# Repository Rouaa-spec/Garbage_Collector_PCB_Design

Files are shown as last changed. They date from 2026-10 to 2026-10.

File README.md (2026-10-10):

# [Hardware Design] Carte Électronique de Contrôle — Robot Autonome Tri-Canettes

Ce dépôt rassemble les fichiers de conception matérielle de la carte de contrôle dédiée à un robot autonome de collecte et de tri de déchets. 

La carte centralise la gestion de l'alimentation (Li-Ion), le pilotage des moteurs DC et l'acquisition des capteurs de navigation sur bus partagés.

📌 **Statut du projet :** 
* 🟧 **Routage PCB (KiCad) :** En cours de réalisation...

---

## 🗺️ Architecture Système 

Le schéma architectural conçu pour la carte :

<p align="center">
Schéma fonctionnel
</p> 

---

## 🛠️ Spécifications & Choix des Composants

### 1. Unité de Traitement & Logique (MCU)
* **Microcontrôleur :** **STM32G431RBT6** (Cortex-M4, 170 MHz). Sélectionné pour ses timers avancés (gestion des moteurs et servo) et sa large connectivité matérielle.

### 2. Gestion de l'Énergie (Power Management)
* **Contrôleur de Charge :** **bq25896RTWR** (Switching Charger). Assure la charge rapide de la batterie Lithium-Ion via USB-C et la gestion dynamique du chemin de puissance (Power Path).
* **Jauge de Batterie :** **bq27220** (Fuel Gauge). Suivi précis de l'état de charge (SoC) via le bus I²C2.
* **Régulation :** LDO **AP2112K-3.3** (600mA) pour l'alimentation stable de la section logique et des capteurs.

### 3. Contrôle des Actionneurs (Motor Drive)
* **Driver Moteurs :** **DRV8833** (Double Pont en H) pour le pilotage de 2 motoréducteurs CC (CH-N20-3) via signaux PWM (`TIM1` et `TIM3`).
* **Servomoteur :** Sortie dédiée pour un **Servo MG90S** (Pince de préhension) piloté par le timer `TIM15`.

### 4. Acquisition Capteurs (Sensors)
Répartition sur trois bus physiques I²C indépendants pour éviter la saturation et les conflits d'adresses :
* **Bus I²C1 :** Centrale inertielle IMU **MPU-6050** (Odométrie).
* **Bus I²C2 :** Section Power Management (**bq27220** et **bq25896**).
* **Bus I²C3 :** Télémètres Laser ToF **VL53L0X** (Évitement d'obstacles) et capteur de couleur/proximité **APDS9960** (Tri des canettes). 
  * *Note de conception :* Les broches `XSHUT` des VL53L0X sont routées vers des GPIOs du STM32 pour configurer leurs adresses de manière logicielle et séquentielle.

---

## 📄 Dossier de Conception (Schématiques)

### Étage Microcontrôleur (MCU)
<p align="center">
MCU
</p> 

### Gestion d'Énergie (Power Management)
<p align="center">
Power Management
</p> 

### Bloc Capteurs (Sensors)
<p align="center">
Sensors
</p>

### Commande Moteurs (Motor Drive)
<p align="center">
Motor Drive
</p>

---

## 📂 Organisation du Dépôt

```text
├── 📂 Hardware/               # Fichiers sources CAO KiCad (.kicad_sch, .kicad_pcb en cours)
├── 📂 Documents/              
│   ├── 📄 Schematic_Print.pdf # Schématique complet 
└── 📄 README.md
```

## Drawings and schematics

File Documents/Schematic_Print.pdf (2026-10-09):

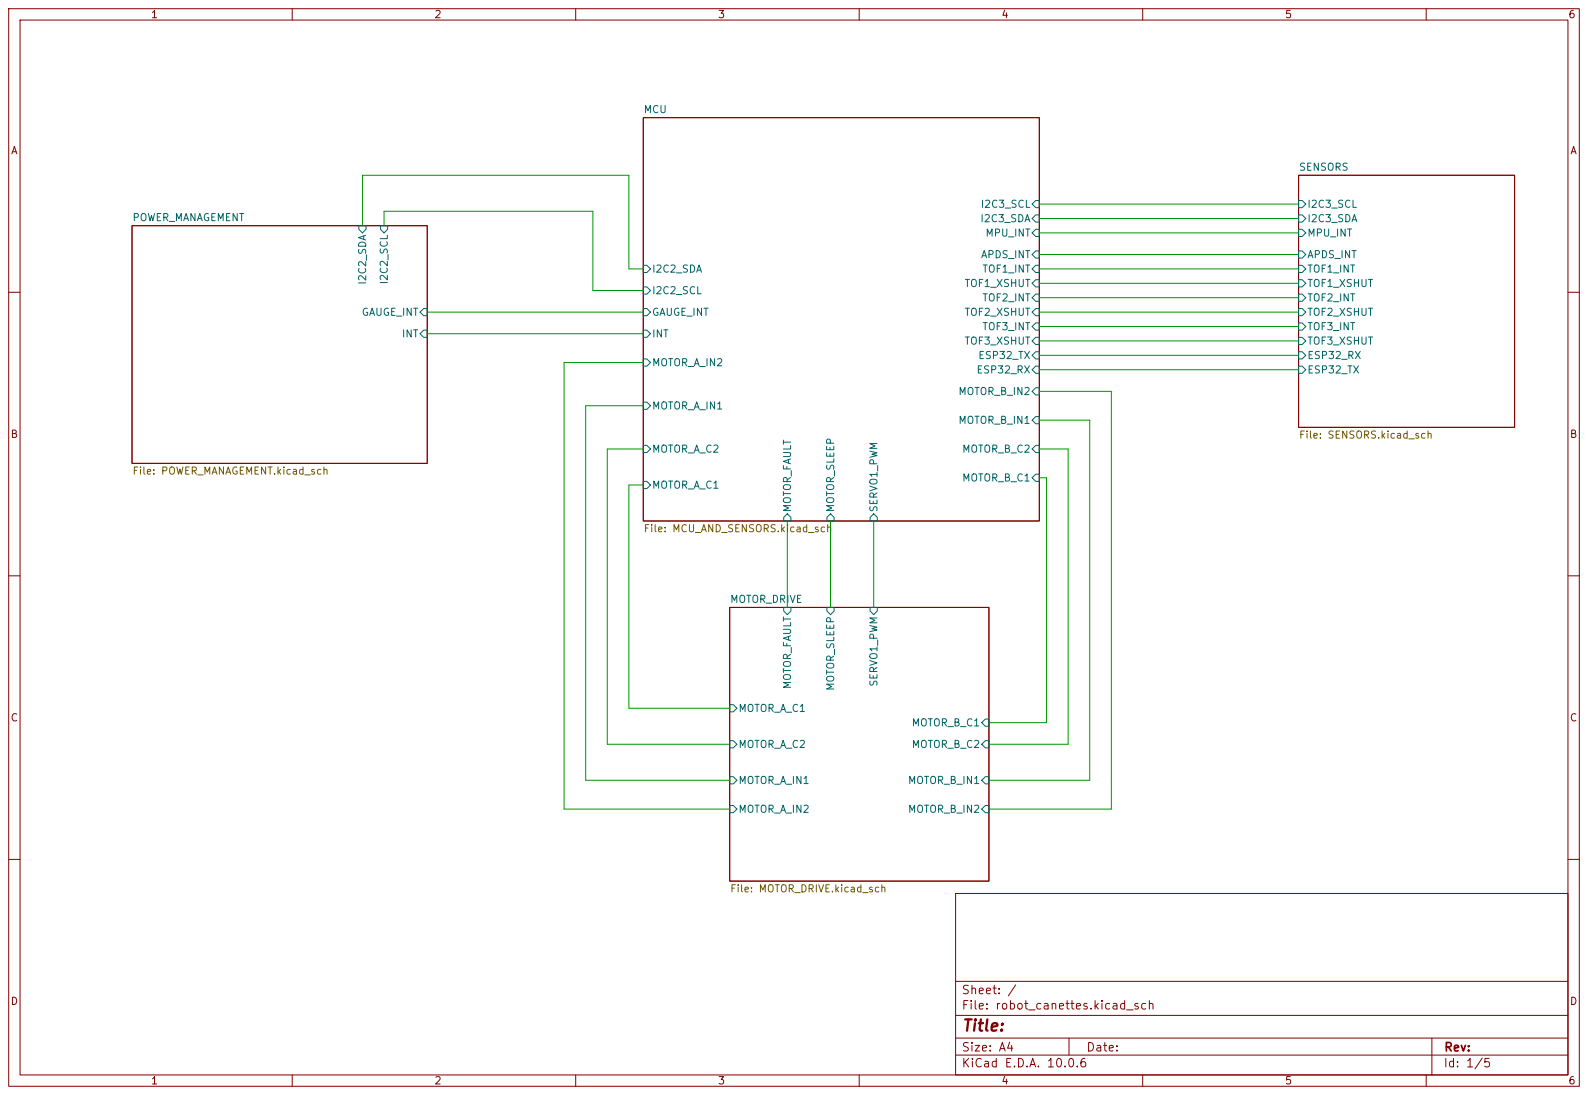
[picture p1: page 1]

Size: A4 | Rev:
KiCad E.D.A. 10.0.6 | Id: 1/5

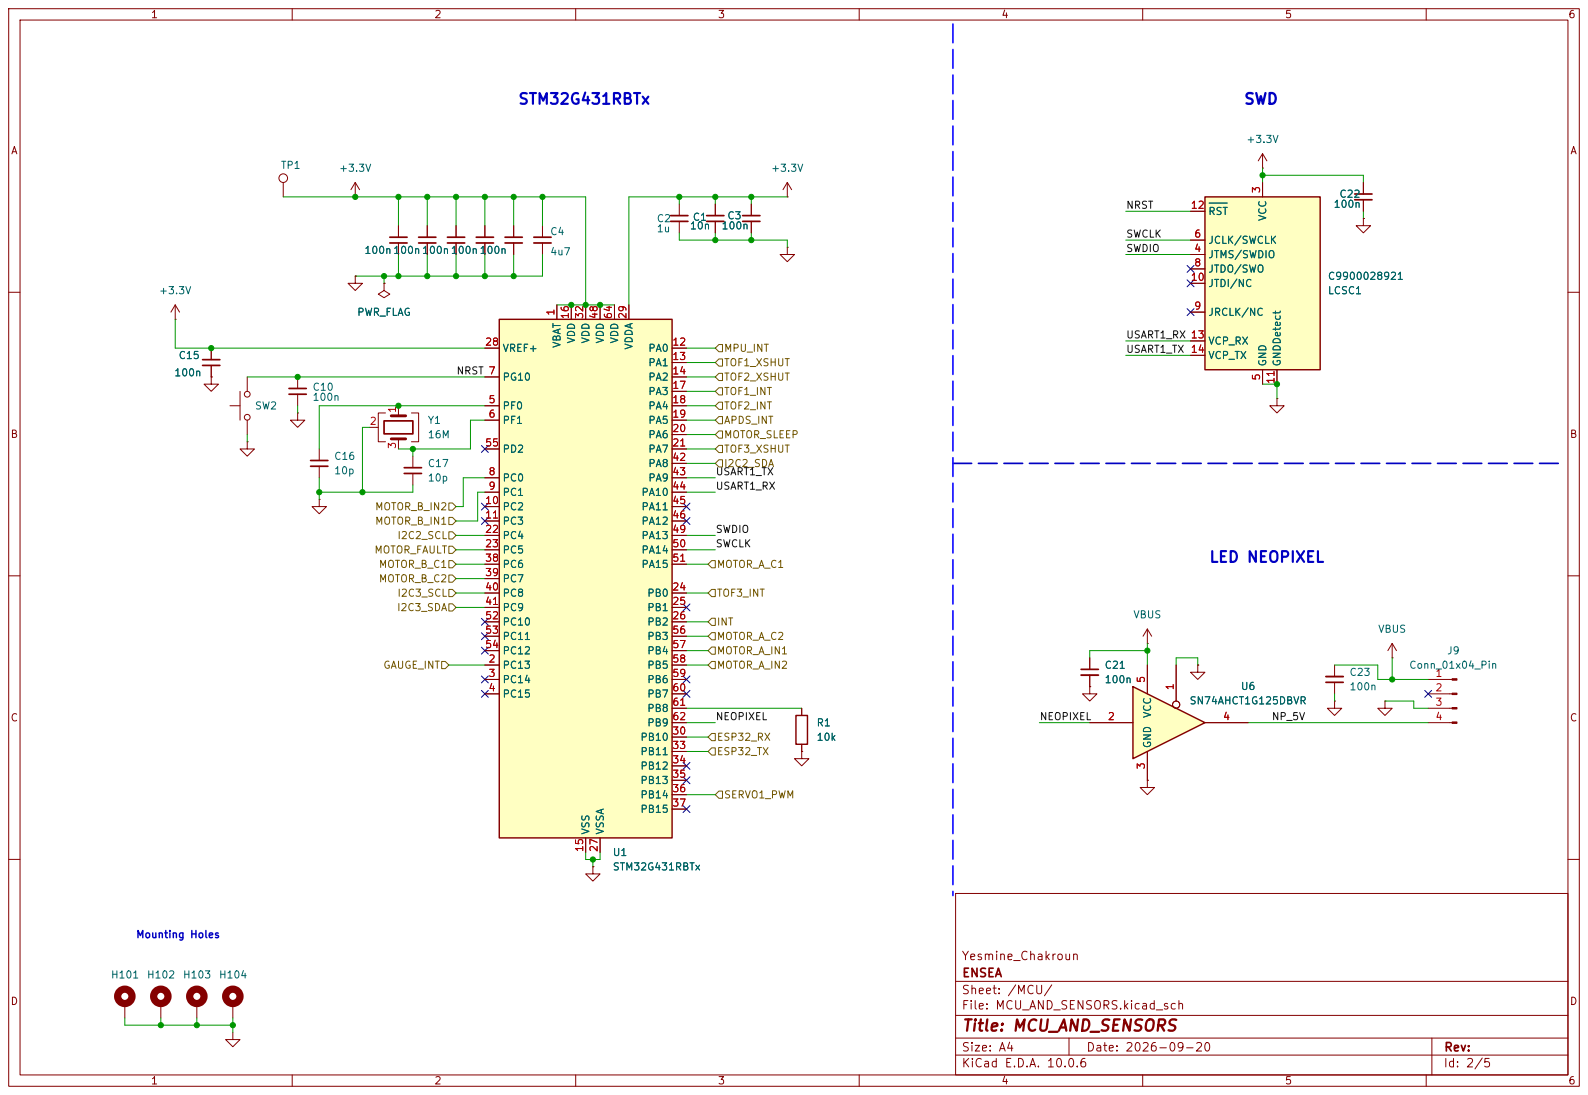
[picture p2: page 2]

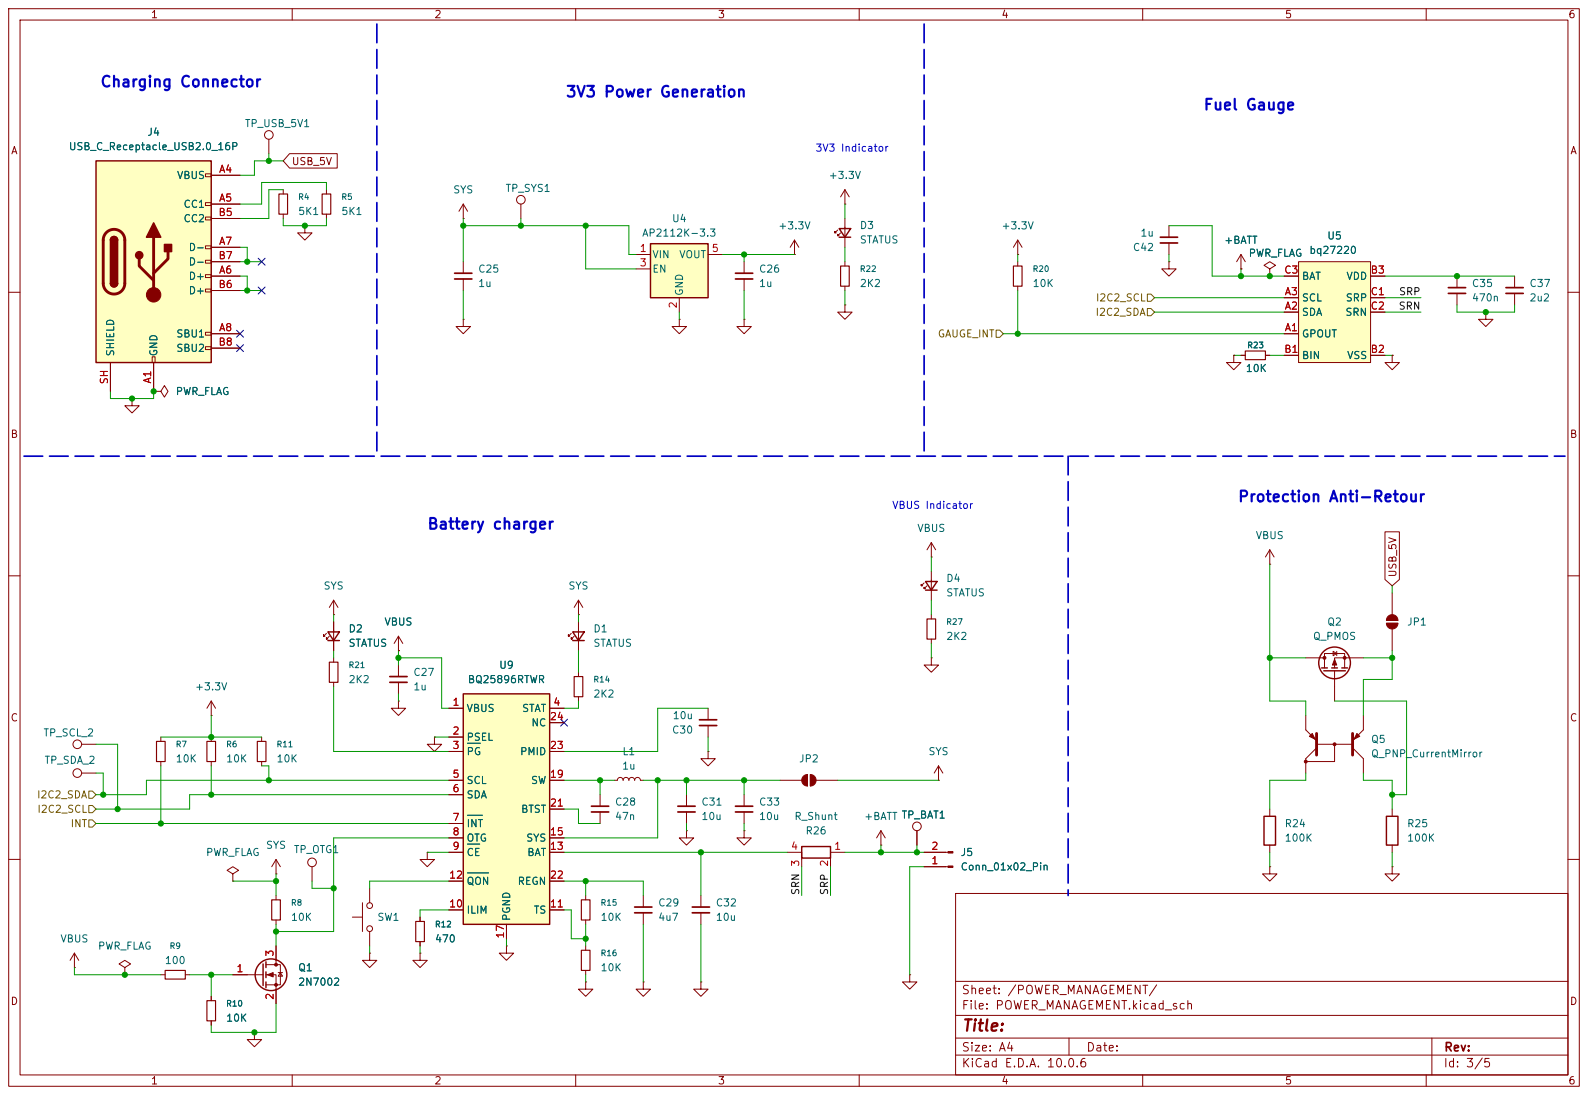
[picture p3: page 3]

VBUS Indicator 3V3 Power Generation

SW 19 BTST 21 REGN 22 PMID 23 NC 24 D2
STATUS

SW 19 BTST 21 REGN 22 PMID 23 NC 24 U9 BQ25896RTWR C27

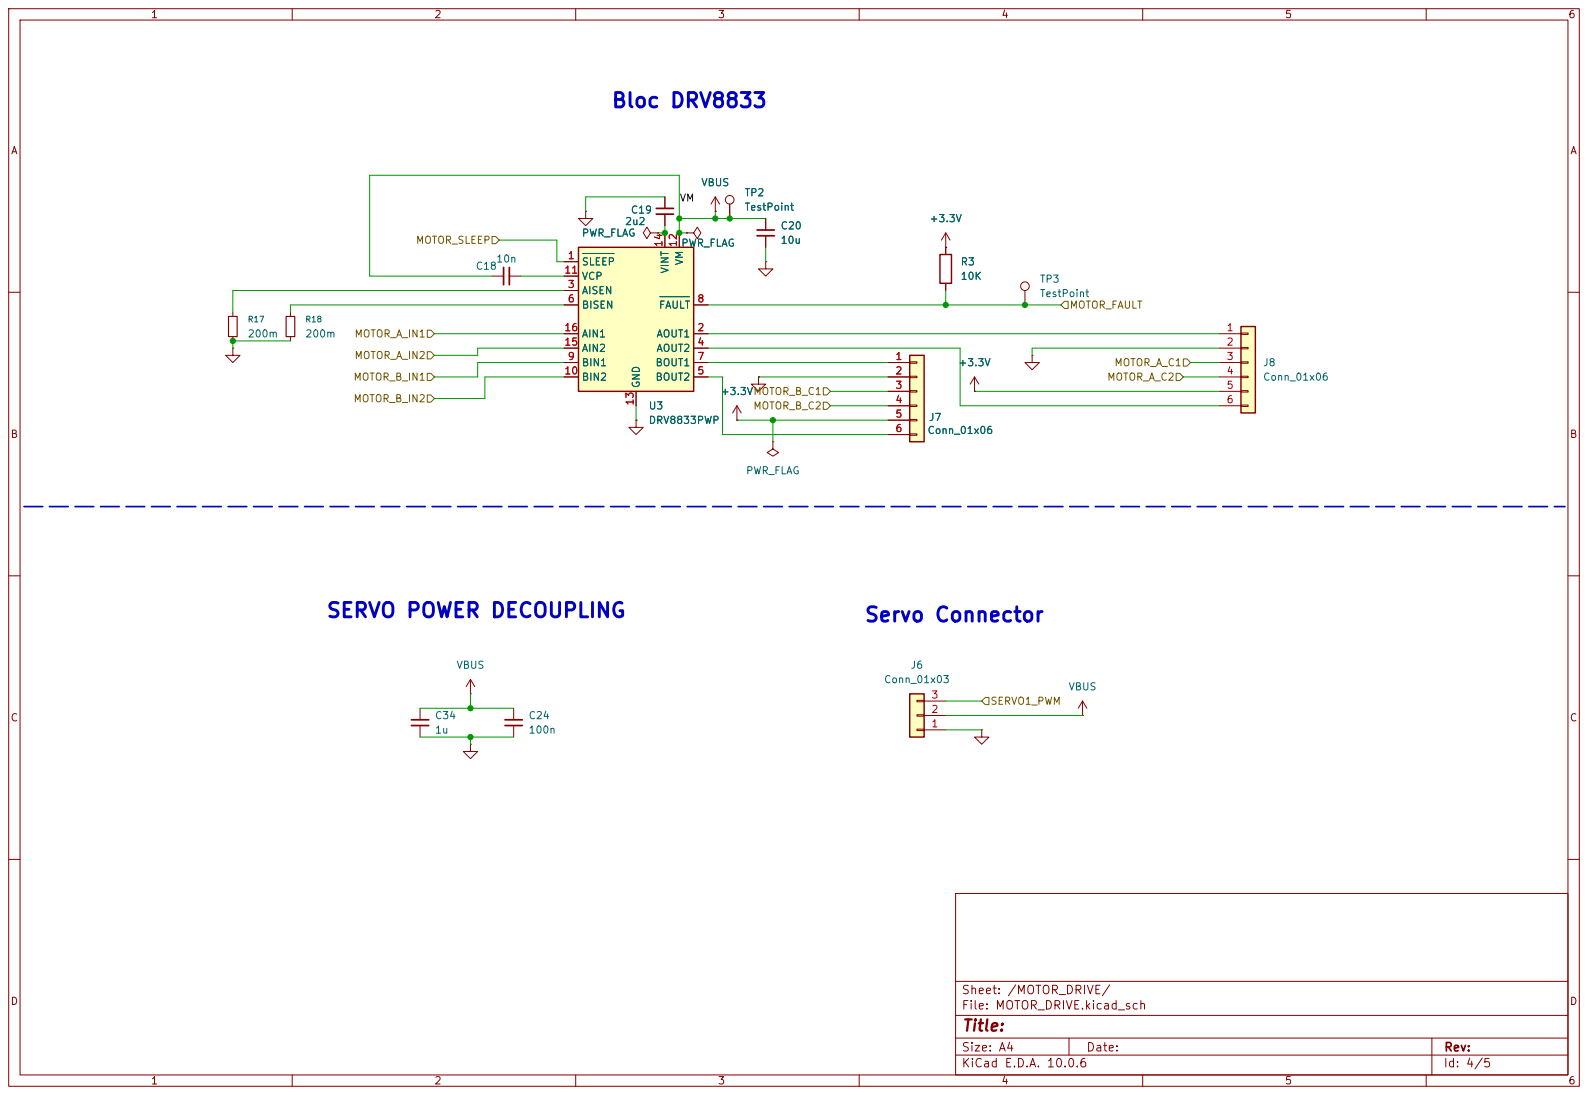
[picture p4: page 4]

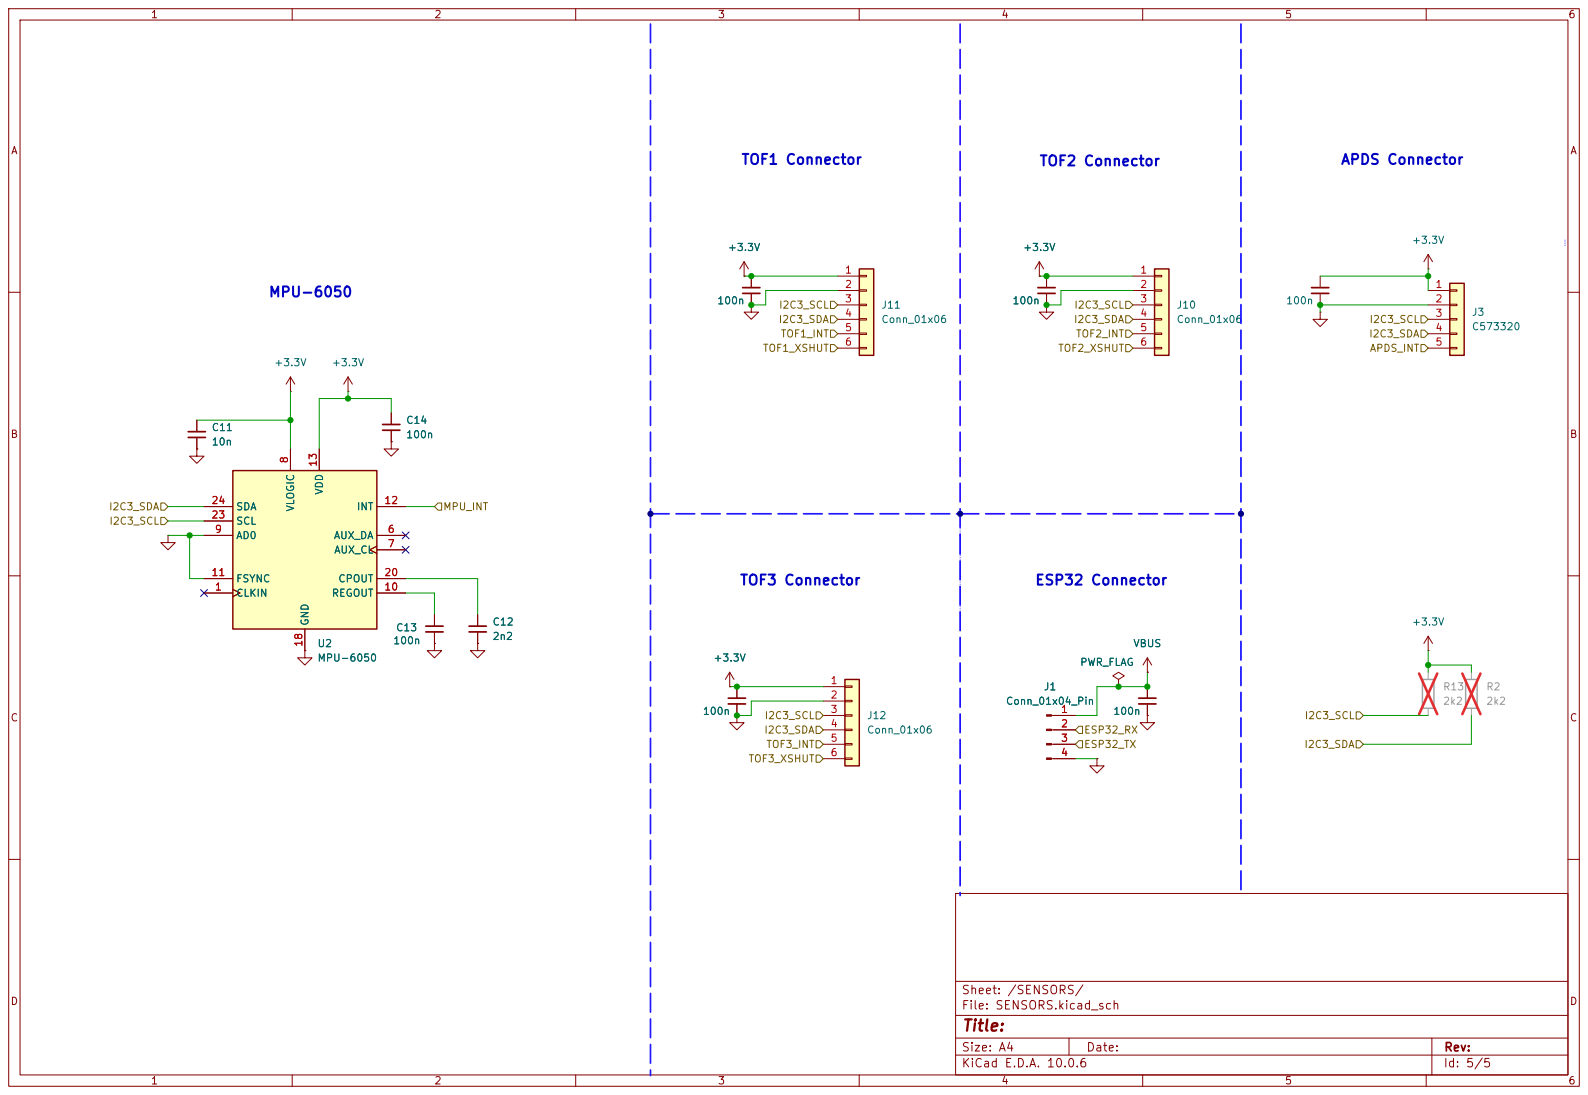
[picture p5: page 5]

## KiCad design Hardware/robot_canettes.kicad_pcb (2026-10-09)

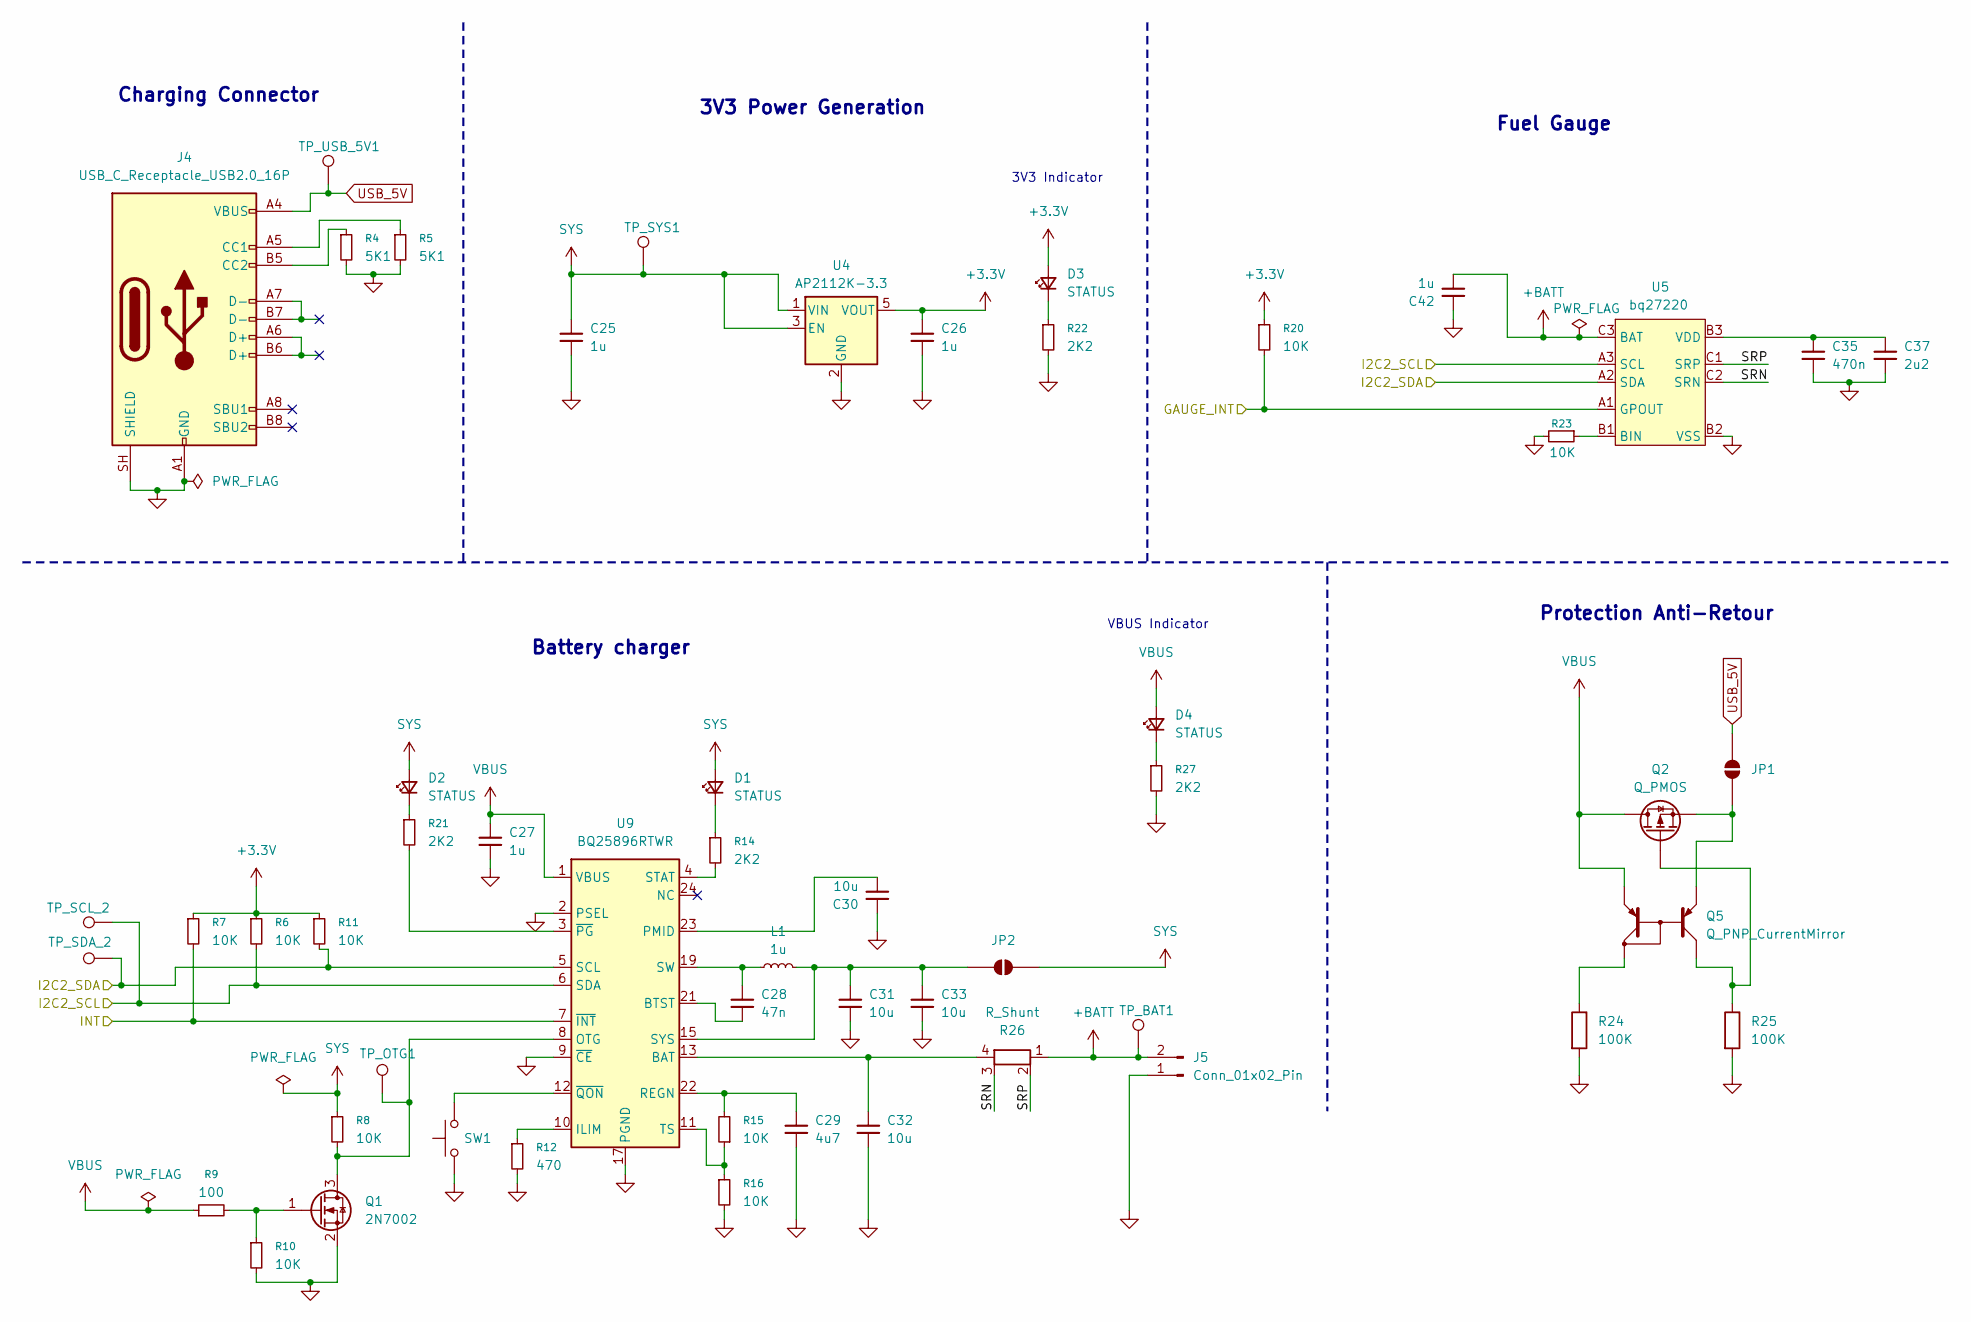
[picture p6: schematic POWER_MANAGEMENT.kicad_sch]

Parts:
C25, C26, C27, C42: 1u; C_0402_1005Metric; JLCPCB Part # C52923
C28: 47n; C_0402_1005Metric; JLCPCB Part # C5254486
C29: 4u7; C_0402_1005Metric; JLCPCB Part # C368809
C30, C31, C32, C33: 10u; C_0603_1608Metric; JLCPCB Part # C19702
C35: 470n; C_0402_1005Metric; JLCPCB Part # C2443202
C37: 2u2; C_0402_1005Metric; JLCPCB Part # C107370
D1: STATUS; LED_0603_1608Metric; JLCPCB Part # C2287
D2, D3, D4: STATUS; LED_0603_1608Metric; JLCPCB Part # C72043
J4: USB_C_Receptacle_USB2.0_16P; USB_C_Receptacle_GCT_USB4105-xx-A_16P_TopMnt_Horizontal; JLCPCB Part # C2765186
J5: Conn_01x02_Pin; JST_PH_B2B-PH-K_1x02_P2.00mm_Vertical
JP1, JP2: SolderJumper-2_P1.3mm_Open_Pad1.0x1.5mm
L1: 1u; L_APV_ANR4010; JLCPCB Part # C354578
Q1: 2N7002; SOT-23; JLCPCB Part # C8485
Q2: Q_PMOS; SOT-23; JLCPCB Part # C177033
Q5: Q_PNP_CurrentMirror; SOT-363_SC-70-6; JLCPCB Part # C42387345
R4, R5: 5K1; R_0402_1005Metric; JLCPCB Part # C25905
R6, R7, R8, R10, R11, R15, R16, R20, R23: 10K; R_0402_1005Metric; JLCPCB Part # C844714
R9: 100; R_0402_1005Metric; JLCPCB Part # C25076
R12: 470; R_0402_1005Metric; JLCPCB Part # C25117
R14, R21, R22, R27: 2K2; R_0402_1005Metric; JLCPCB Part # C25879
R24, R25: 100K; R_0603_1608Metric; JLCPCB Part # C25803
R26: R_Shunt; R_Shunt_Ohmite_LVK12; JLCPCB Part # C500740
SW1: SW_SPST_Omron_B3FS-101xP; JLCPCB Part # C271753
TP_BAT1: TestPoint_Pad_D1.5mm
TP_OTG1: TestPoint_Pad_D1.5mm
TP_SCL_2: TestPoint_Pad_D1.5mm
TP_SDA_2: TestPoint_Pad_D1.5mm
TP_SYS1: TestPoint_Pad_D1.5mm
TP_USB_5V1: TestPoint_Pad_D1.5mm
U4: AP2112K-3.3; SOT-23-5; JLCPCB Part # C51118
U5: bq27220; BGA-9_3x3_1.62x1.58mm_Pitch0.5mm; JLCPCB Part # C528617
U9: BQ25896RTWR; Texas_RTW_WQFN-24-1EP_4x4mm_P0.5mm_EP2.7x2.7mm_ThermalVias; JLCPCB Part # C181475

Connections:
+3.3V: C26.1, D3.2 (A), R6.1, R7.1, R11.1, R20.1, U4.5 (VOUT); also elsewhere on the board
+BATT: C42.2, J5.2, R26.1, TP_BAT1.1 (1_1), U5.C3 (BAT)
/MCU/GAUGE_INT: R20.2, U5.A1 (GPOUT); also elsewhere on the board
/MCU/I2C2_SCL: R6.2, TP_SCL_2.1 (1_1), U5.A3 (SCL), U9.6 (SDA); also elsewhere on the board
/MCU/I2C2_SDA: R11.2, TP_SDA_2.1 (1_1), U5.A2 (SDA), U9.5 (SCL); also elsewhere on the board
/MCU/INT: R7.2, U9.7 (~INT); also elsewhere on the board
/POWER_MANAGEMENT/SRN: R26.3, U5.C2 (SRN)
/POWER_MANAGEMENT/SRP: R26.2, U5.C1 (SRP)
unnamed: C28.1, L1.1, U9.19 (SW), U9.20 (SW)
unnamed: C32.1, R26.4, U9.13 (BAT), U9.14 (BAT)
unnamed: D1.1 (K), R14.1
unnamed: D2.1 (K), R21.1
unnamed: D3.1 (K), R22.1
unnamed: D4.1 (K), R27.1
unnamed: J4.A5 (CC1), R5.1
unnamed: J4.B5 (CC2), R4.1
unnamed: JP1.1 (A), Q2.2 (S), Q5.1 (E1)
unnamed: C31.1, C33.1, JP2.2 (B), L1.2, U9.15 (SYS), U9.16 (SYS)
unnamed: Q1.3 (D), R8.2, TP_OTG1.1 (1_1), U9.8 (OTG)
unnamed: Q1.1 (G), R9.2, R10.1
unnamed: Q2.1 (G), Q5.6 (C1), R25.1
unnamed: Q5.3 (C2), R24.1
unnamed: R23.1, U5.B1 (BIN)
unnamed: C35.1, C37.1, U5.B3 (VDD)
unnamed: C28.2, U9.21 (BTST)
unnamed: R12.1, U9.10 (ILIM)
unnamed: C30.2, U9.23 (PMID)
unnamed: C29.1, R15.2, U9.22 (REGN)
unnamed: R14.2, U9.4 (STAT)
unnamed: R15.1, R16.1, U9.11 (TS)
unnamed: R21.2, U9.3 (~PG)
unnamed: SW1.2, U9.12 (~QON)
SYS: C25.1, D1.2 (A), D2.2 (A), JP2.1 (A), R8.1, TP_SYS1.1 (1_1), U4.1 (VIN), U4.3 (EN)
USB_5V: J4.A4 (VBUS), J4.A9 (VBUS), J4.B4 (VBUS), J4.B9 (VBUS), JP1.2 (B), TP_USB_5V1.1 (1_1)
VBUS: C27.1, D4.2 (A), Q2.3 (D), Q5.4 (E2), R9.1, U9.1 (VBUS); also elsewhere on the board

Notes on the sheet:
Battery charger
Charging Connector
3V3 Indicator
Fuel Gauge
3V3 Power Generation
Protection Anti-Retour
VBUS Indicator

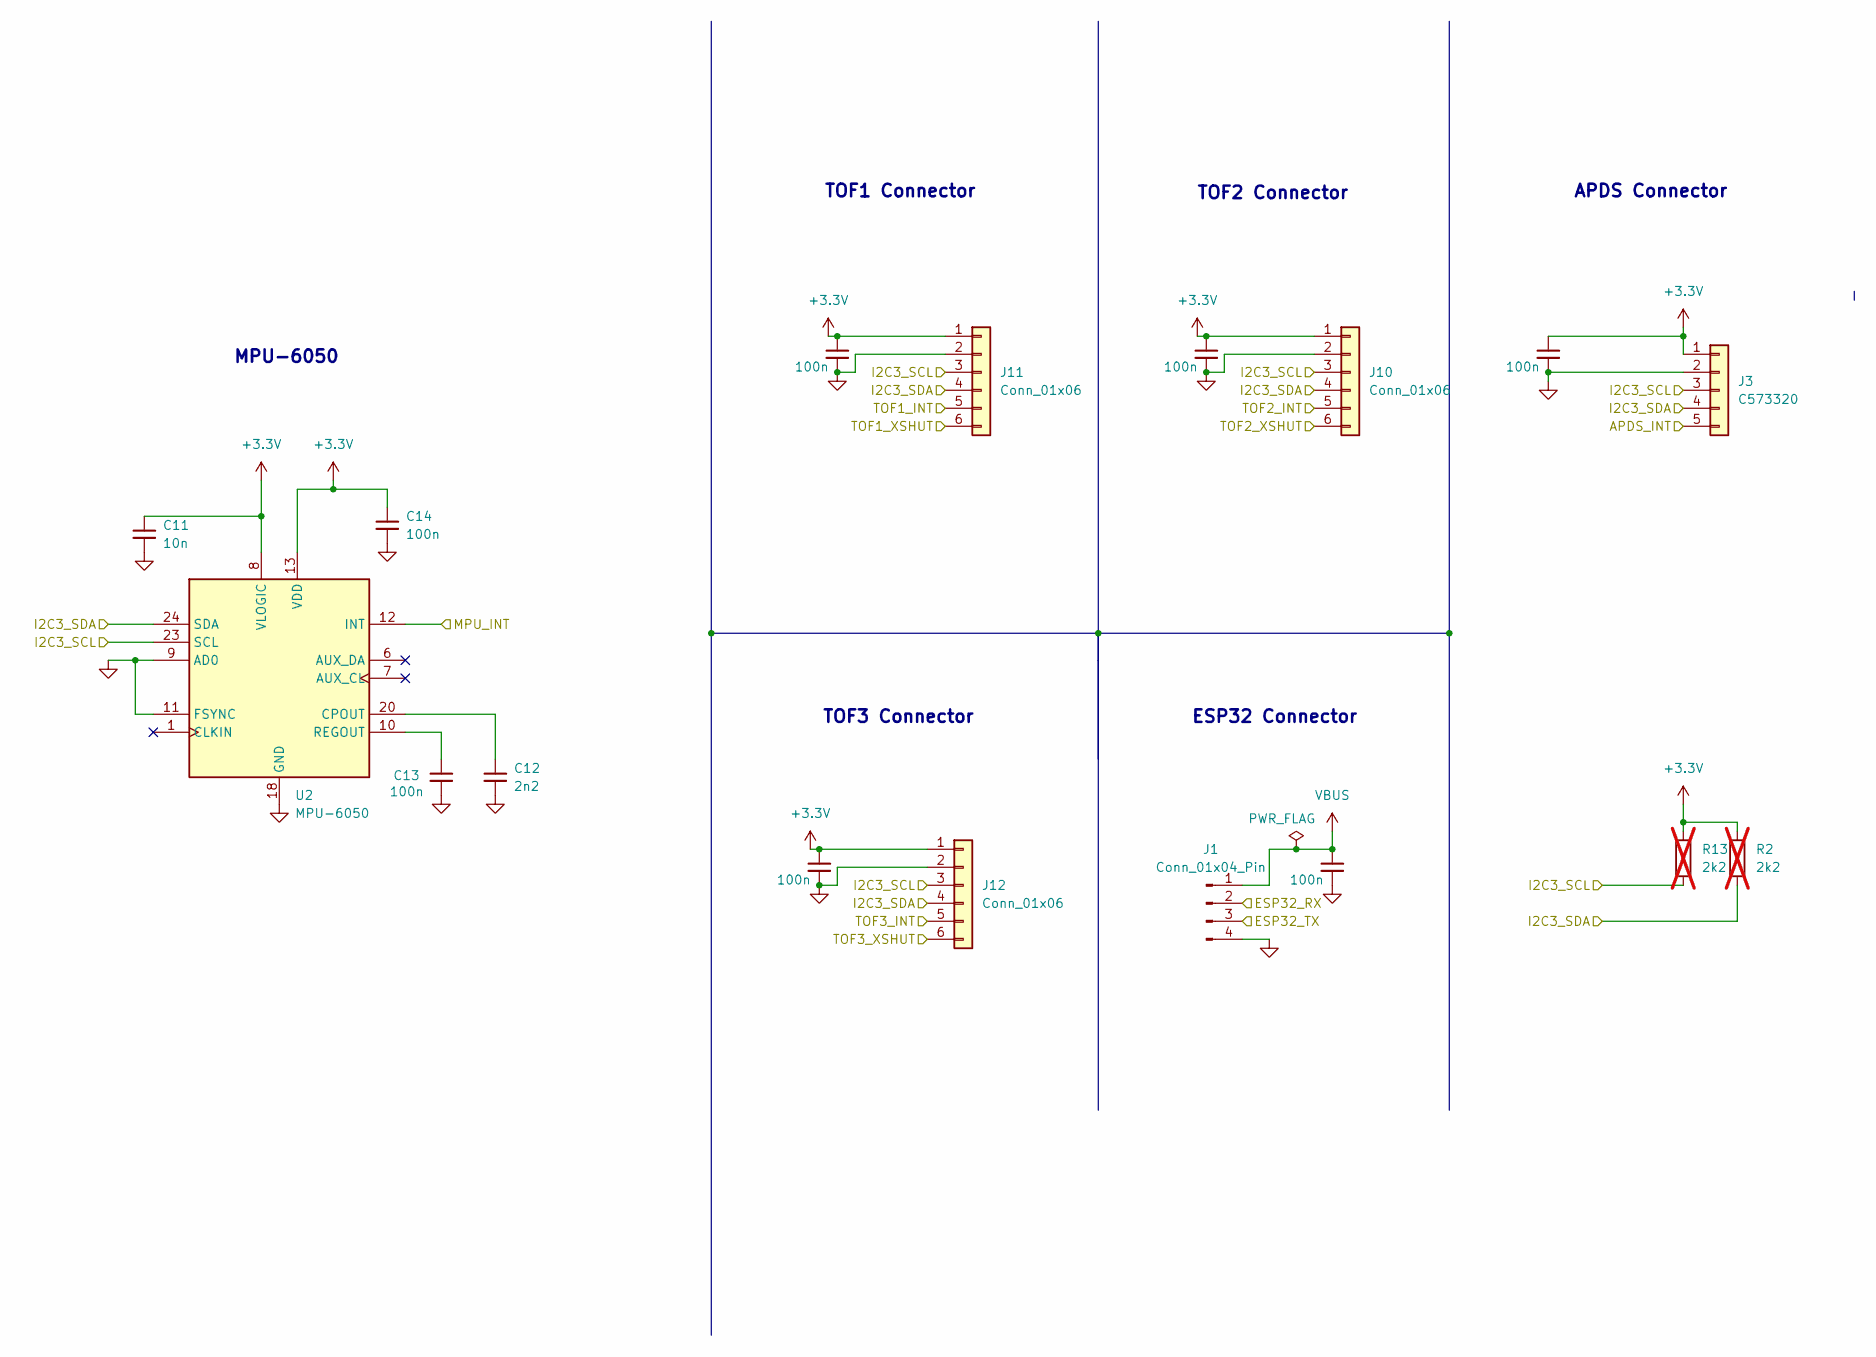
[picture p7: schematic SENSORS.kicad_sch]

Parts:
C11: 10n; C_0402_1005Metric; JLCPCB PART # C15195
C12: 2n2; C_0402_1005Metric; JLCPCB PART # C1531
C13, C14, C38, C39, C40, C41, C43: 100n; C_0402_1005Metric; JLCPCB PART # C1525
J1: Conn_01x04_Pin; JST_PH_B4B-PH-K_1x04_P2.00mm_Vertical
J3: C573320; JST_PH_B5B-PH-K_1x05_P2.00mm_Vertical; JLCPCB PART# C573320
J10, J11, J12: Conn_01x06; JST_PH_B6B-PH-K_1x06_P2.00mm_Vertical
R2, R13: 2k2; R_0402_1005Metric; JLCPCB PART # C174143; not fitted
U2: MPU-6050; InvenSense_QFN-24_4x4mm_P0.5mm; JLCPCB PART # C24112

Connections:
+3.3V: C11.1, C14.1, C38.1, C39.1, C40.1, C41.1, J3.1, J10.1, J11.1, J12.1, R2.1, R13.1, U2.8 (VLOGIC), U2.13 (VDD); also elsewhere on the board
/MCU/APDS_INT: J3.5; also elsewhere on the board
/MCU/ESP32_RX: J1.3; also elsewhere on the board
/MCU/ESP32_TX: J1.2; also elsewhere on the board
/MCU/I2C3_SCL: J3.3, J10.3, J11.3, J12.3, R13.2, U2.23 (SCL); also elsewhere on the board
/MCU/I2C3_SDA: J3.4, J10.4, J11.4, J12.4, R2.2, U2.24 (SDA); also elsewhere on the board
/MCU/MPU_INT: U2.12 (INT); also elsewhere on the board
/MCU/TOF1_INT: J12.5; also elsewhere on the board
/MCU/TOF1_XSHUT: J12.6; also elsewhere on the board
/MCU/TOF2_INT: J10.5; also elsewhere on the board
/MCU/TOF2_XSHUT: J10.6; also elsewhere on the board
/MCU/TOF3_INT: J11.5; also elsewhere on the board
/MCU/TOF3_XSHUT: J11.6; also elsewhere on the board
unnamed: C12.1, U2.20 (CPOUT)
unnamed: C13.1, U2.10 (REGOUT)
VBUS: C43.1, J1.1; also elsewhere on the board

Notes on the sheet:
TOF1 Connector
APDS Connector
ESP32 Connector
TOF2 Connector
MPU-6050
TOF3 Connector

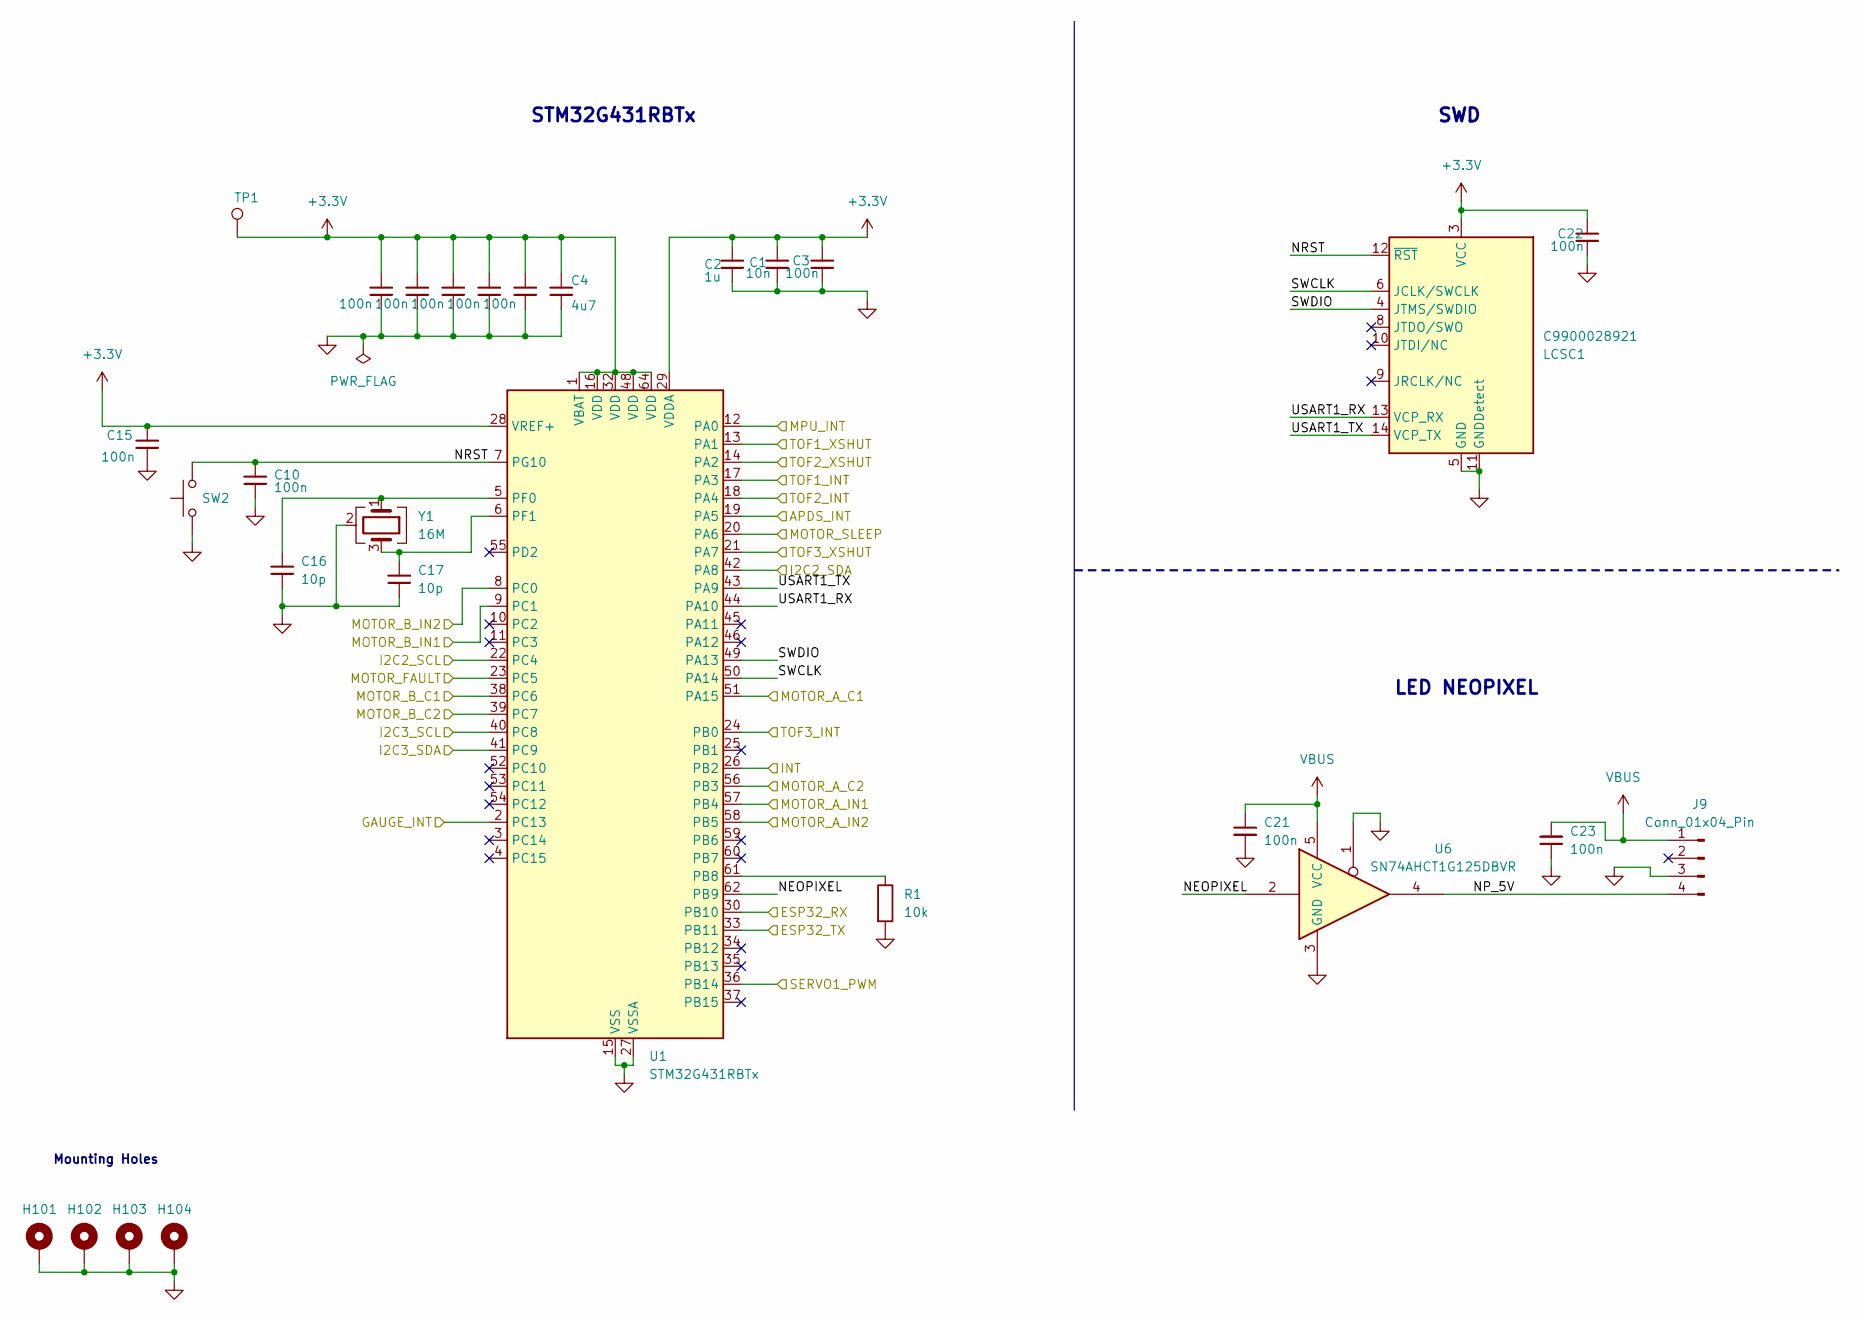
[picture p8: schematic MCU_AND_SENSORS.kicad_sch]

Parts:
C1: 10n; C_0402_1005Metric; JLCPCB PART# C15195
C2: 1u; C_0603_1608Metric; JLCPCB PART # C141772
C3, C6, C7, C8, C9, C10, C15, C22: 100n; C_0402_1005Metric; JLCPCB PART # C1525
C4: 4u7; C_0603_1608Metric
C5: 100n; C_0402_1005Metric
C16, C17: 10p; C_0603_1608Metric; JLCPCB PART # C123155
C21, C23: 100n; C_0402_1005Metric; JLCPCB Part # C1525
H101, H102, H103, H104: MountingHole_Pad; MountingHole_3.2mm_M3_Pad_Via
J9: Conn_01x04_Pin; JST_PH_B4B-PH-K_1x04_P2.00mm_Vertical; JLCPCB Part # C2691448
LCSC1: C9900028921; PinHeader_2x07_P1.27mm_Vertical_SMD; JLCPCB PART # C9900028921
R1: 10k; R_0402_1005Metric; JLCPCB PART # C174175
SW2: SW_SPST_Omron_B3FS-101xP; JLCPCB Part # C271753
TP1: TestPoint; TestPoint_Pad_D1.5mm
U1: STM32G431RBTx; LQFP-64_10x10mm_P0.5mm; JLCPCB PART # C431633
U6: SN74AHCT1G125DBVR; SOT-23-5; JLCPCB Part # C20617903
Y1: 16M; Crystal_SMD_EuroQuartz_MT-4Pin_3.2x2.5mm; JLCPCB PART # C13738

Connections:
+3.3V: C1.1, C2.1, C3.1, C4.1, C5.1, C6.1, C7.1, C8.1, C9.1, C15.1, C22.1, LCSC1.3 (VCC), TP1.1 (1_1), U1.1 (VBAT), U1.16 (VDD), U1.28 (VREF+), U1.29 (VDDA), U1.32 (VDD), U1.48 (VDD), U1.64 (VDD); also elsewhere on the board
/MCU/APDS_INT: U1.19 (PA5); also elsewhere on the board
/MCU/ESP32_RX: U1.30 (PB10); also elsewhere on the board
/MCU/ESP32_TX: U1.33 (PB11); also elsewhere on the board
/MCU/GAUGE_INT: U1.2 (PC13); also elsewhere on the board
/MCU/I2C2_SCL: U1.22 (PC4); also elsewhere on the board
/MCU/I2C2_SDA: U1.42 (PA8); also elsewhere on the board
/MCU/I2C3_SCL: U1.40 (PC8); also elsewhere on the board
/MCU/I2C3_SDA: U1.41 (PC9); also elsewhere on the board
/MCU/INT: U1.26 (PB2); also elsewhere on the board
/MCU/MOTOR_A_C1: U1.51 (PA15); also elsewhere on the board
/MCU/MOTOR_A_C2: U1.56 (PB3); also elsewhere on the board
/MCU/MOTOR_A_IN1: U1.57 (PB4); also elsewhere on the board
/MCU/MOTOR_A_IN2: U1.58 (PB5); also elsewhere on the board
/MCU/MOTOR_B_C1: U1.38 (PC6); also elsewhere on the board
/MCU/MOTOR_B_C2: U1.39 (PC7); also elsewhere on the board
/MCU/MOTOR_B_IN1: U1.9 (PC1); also elsewhere on the board
/MCU/MOTOR_B_IN2: U1.8 (PC0); also elsewhere on the board
/MCU/MOTOR_FAULT: U1.23 (PC5); also elsewhere on the board
/MCU/MOTOR_SLEEP: U1.20 (PA6); also elsewhere on the board
/MCU/MPU_INT: U1.12 (PA0); also elsewhere on the board
/MCU/NEOPIXEL: U1.62 (PB9), U6.2
/MCU/NP_5V: J9.4, U6.4
/MCU/NRST: C10.1, LCSC1.12 (~RST), SW2.2, U1.7 (PG10)
/MCU/SERVO1_PWM: U1.36 (PB14); also elsewhere on the board
/MCU/SWCLK: LCSC1.6 (JCLK/SWCLK), U1.50 (PA14)
/MCU/SWDIO: LCSC1.4 (JTMS/SWDIO), U1.49 (PA13)
/MCU/TOF1_INT: U1.17 (PA3); also elsewhere on the board
/MCU/TOF1_XSHUT: U1.13 (PA1); also elsewhere on the board
/MCU/TOF2_INT: U1.18 (PA4); also elsewhere on the board
/MCU/TOF2_XSHUT: U1.14 (PA2); also elsewhere on the board
/MCU/TOF3_INT: U1.24 (PB0); also elsewhere on the board
/MCU/TOF3_XSHUT: U1.21 (PA7); also elsewhere on the board
/MCU/USART1_RX: LCSC1.13 (VCP_RX), U1.44 (PA10)
/MCU/USART1_TX: LCSC1.14 (VCP_TX), U1.43 (PA9)
unnamed: R1.1, U1.61 (PB8)
unnamed: C16.1, U1.5 (PF0), Y1.1
unnamed: C17.1, U1.6 (PF1), Y1.3
VBUS: C21.1, C23.2, J9.1, U6.5 (VCC); also elsewhere on the board

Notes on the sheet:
LED NEOPIXEL
SWD
Mounting Holes
STM32G431RBTx

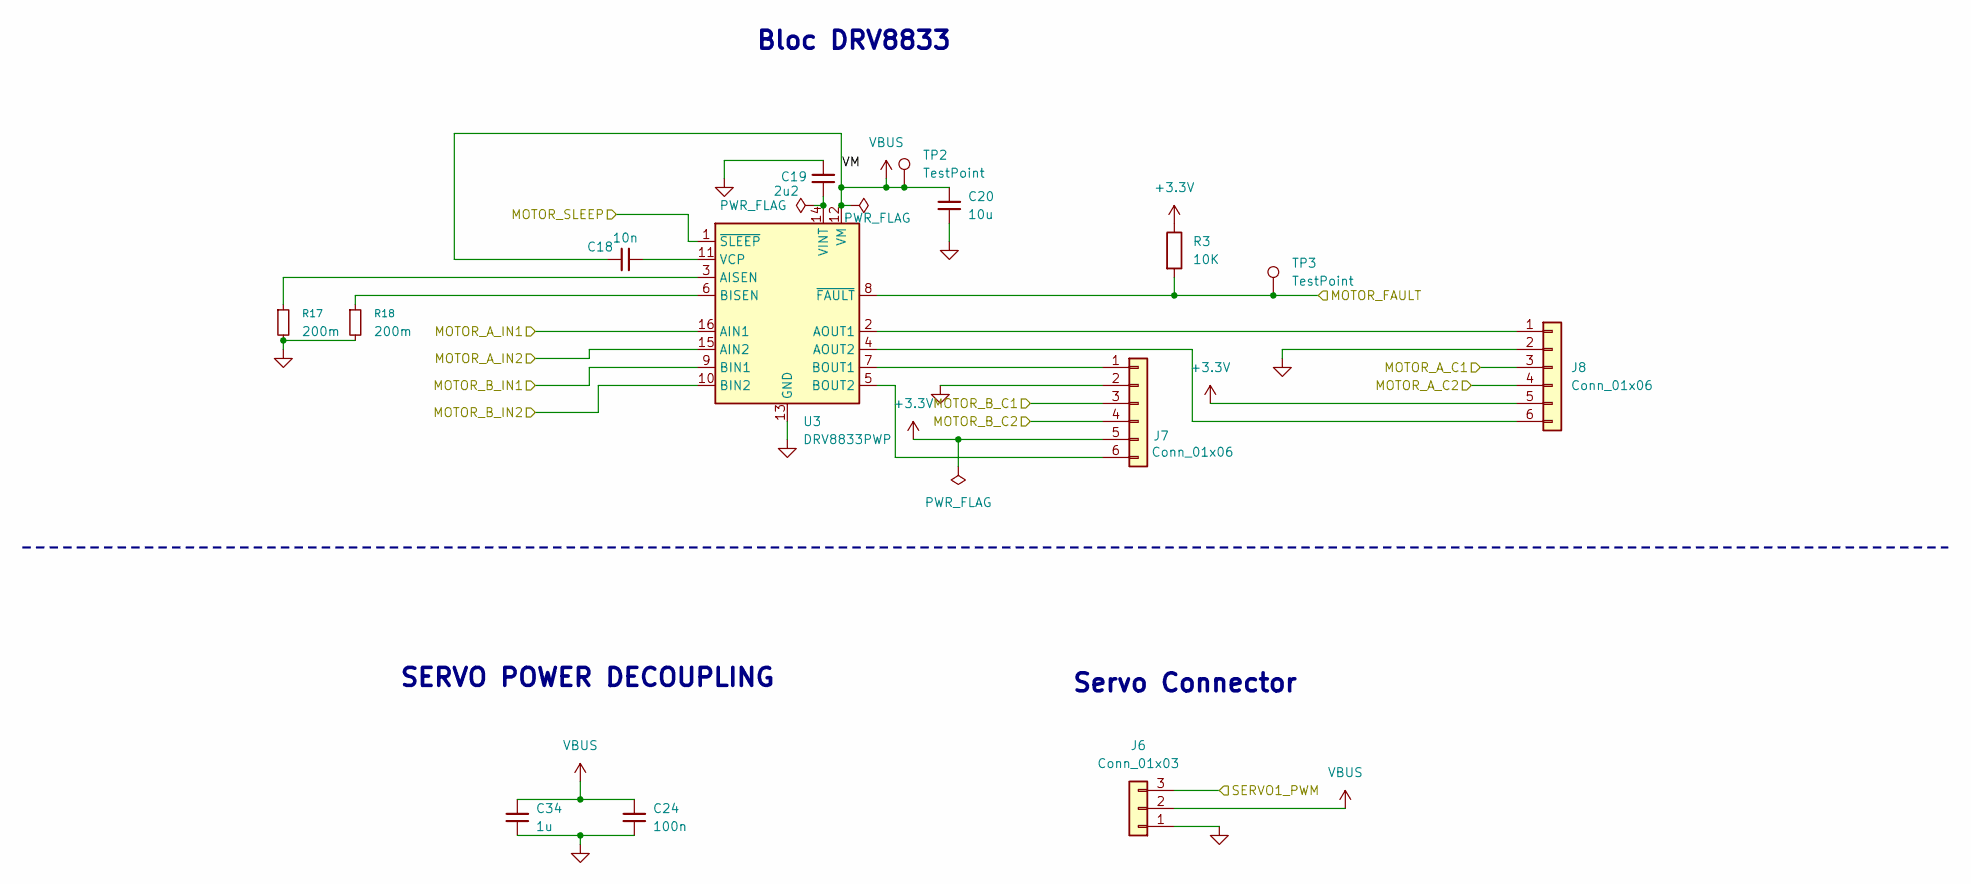
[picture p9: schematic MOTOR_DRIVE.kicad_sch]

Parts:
C18: 10n; C_0402_1005Metric; JLCPCB Part # C15195
C19: 2u2; C_0402_1005Metric; JLCPCB Part # C12530
C20: 10u; C_0805_2012Metric; JLCPCB Part # C380332
C24: 100n; C_0402_1005Metric; JLCPCB Part # C1525
C34: 1u; C_0402_1005Metric
J6: Conn_01x03; JST_PH_B3B-PH-K_1x03_P2.00mm_Vertical; JLCPCB Part # C49257
J7, J8: Conn_01x06; JST_PH_B6B-PH-K_1x06_P2.00mm_Vertical; JLCPCB Part # C265069
R3: 10K; R_0402_1005Metric; JLCPCB Part # C844714
R17, R18: 200m; R_1206_3216Metric; JLCPCB PART # C1727756
TP2, TP3: TestPoint; TestPoint_Pad_D1.5mm
U3: DRV8833PWP; HTSSOP-16-1EP_4.4x5mm_P0.65mm_EP3.4x5mm_Mask2.46x2.31mm; JLCPCB Part # C50506

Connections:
+3.3V: J7.5, J8.5, R3.1; also elsewhere on the board
/MCU/MOTOR_A_C1: J8.3; also elsewhere on the board
/MCU/MOTOR_A_C2: J8.4; also elsewhere on the board
/MCU/MOTOR_A_IN1: U3.16 (AIN1); also elsewhere on the board
/MCU/MOTOR_A_IN2: U3.15 (AIN2); also elsewhere on the board
/MCU/MOTOR_B_C1: J7.3; also elsewhere on the board
/MCU/MOTOR_B_C2: J7.4; also elsewhere on the board
/MCU/MOTOR_B_IN1: U3.9 (BIN1); also elsewhere on the board
/MCU/MOTOR_B_IN2: U3.10 (BIN2); also elsewhere on the board
/MCU/MOTOR_FAULT: R3.2, TP3.1 (1_1), U3.8 (~FAULT); also elsewhere on the board
/MCU/MOTOR_SLEEP: U3.1 (~SLEEP); also elsewhere on the board
/MCU/SERVO1_PWM: J6.3; also elsewhere on the board
unnamed: J7.1, U3.7 (BOUT1)
unnamed: J7.6, U3.5 (BOUT2)
unnamed: J8.1, U3.2 (AOUT1)
unnamed: J8.6, U3.4 (AOUT2)
unnamed: R17.1, U3.3 (AISEN)
unnamed: R18.1, U3.6 (BISEN)
unnamed: C18.2, U3.11 (VCP)
unnamed: C19.2, U3.14 (VINT)
VBUS: C18.1, C20.1, C24.1, C34.1, J6.2, TP2.1 (1_1), U3.12 (VM); also elsewhere on the board

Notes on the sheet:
Servo Connector
SERVO POWER DECOUPLING
Bloc DRV8833

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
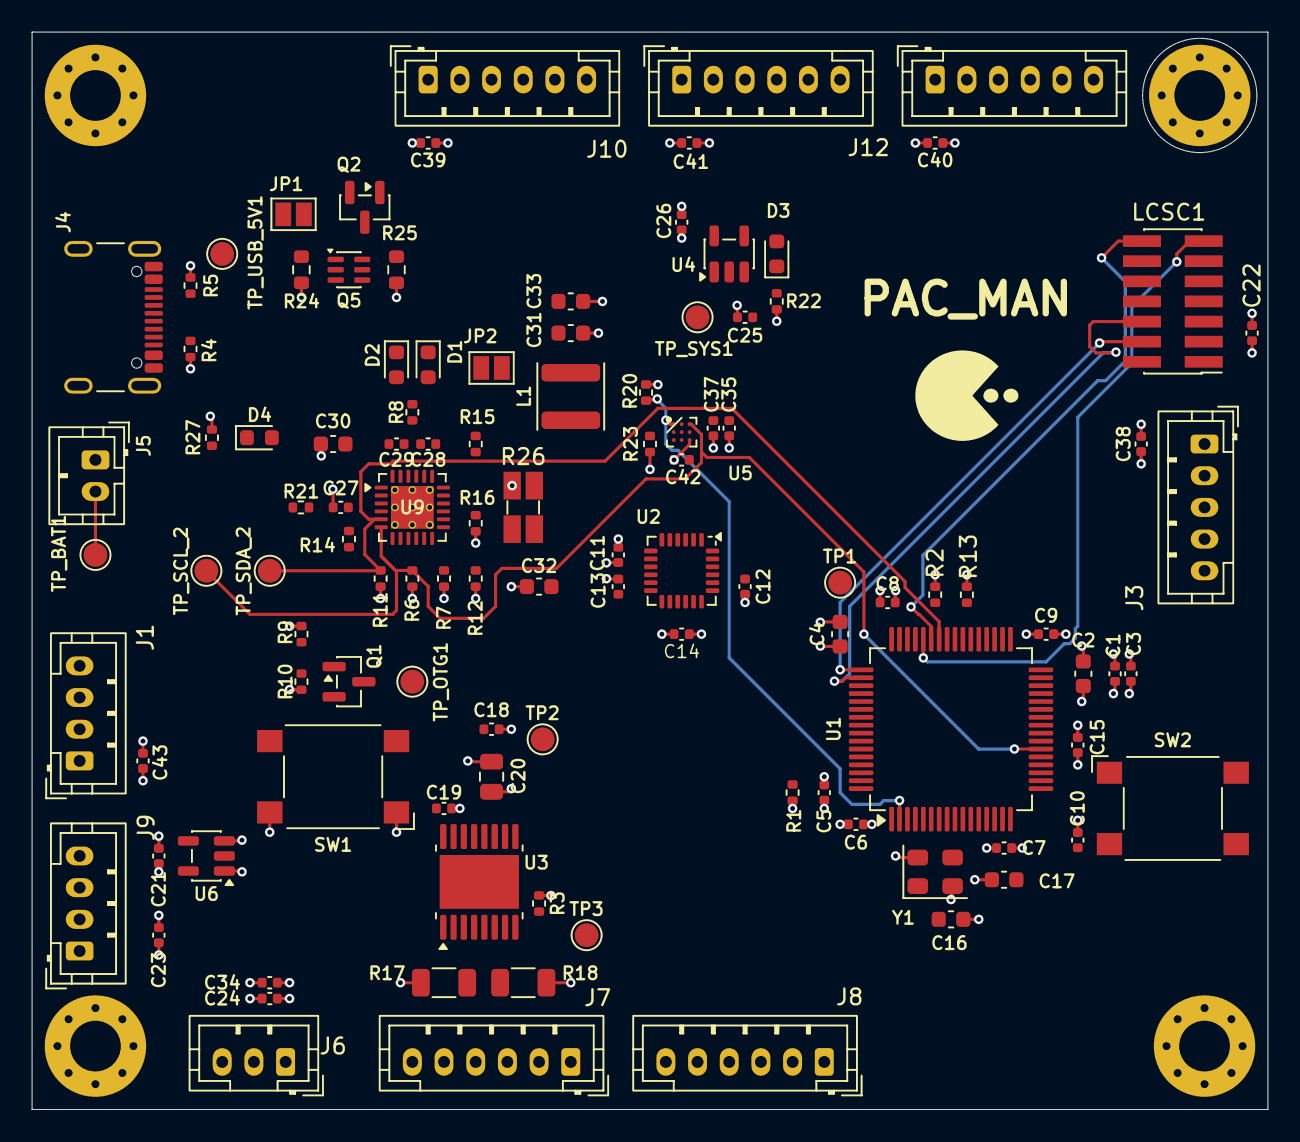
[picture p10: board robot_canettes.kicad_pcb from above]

Board: 4 copper layers, 78.0 x 68.0 mm, 113 parts (0 on the bottom side), 79 nets.

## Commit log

2026-10-09 Mise a jour du README local et des fichiers de conception KiCad
    [MCU_AND_SENSORS.kicad_sch, MOTOR_DRIVE.kicad_sch, POWER_MANAGEMENT.kicad_sch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]
2026-10-09 Schematic update
    [MCU_AND_SENSORS.kicad_sch, MOTOR_DRIVE.kicad_sch, POWER_MANAGEMENT.kicad_sch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]
2026-10-09 Update PCB routing status in README
    Updated project status to indicate PCB routing is ongoing.
2026-10-09 Clarify Schematic_Print.pdf description in README
    Updated the README to clarify the description of the Schematic_Print.pdf file.
